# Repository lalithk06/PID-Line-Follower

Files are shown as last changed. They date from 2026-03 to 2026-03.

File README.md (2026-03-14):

# 🤖 ESP32 Line Follower Robot — Hardware Design
*A compact and efficient line follower robot built using the ESP32*

<p align="center">
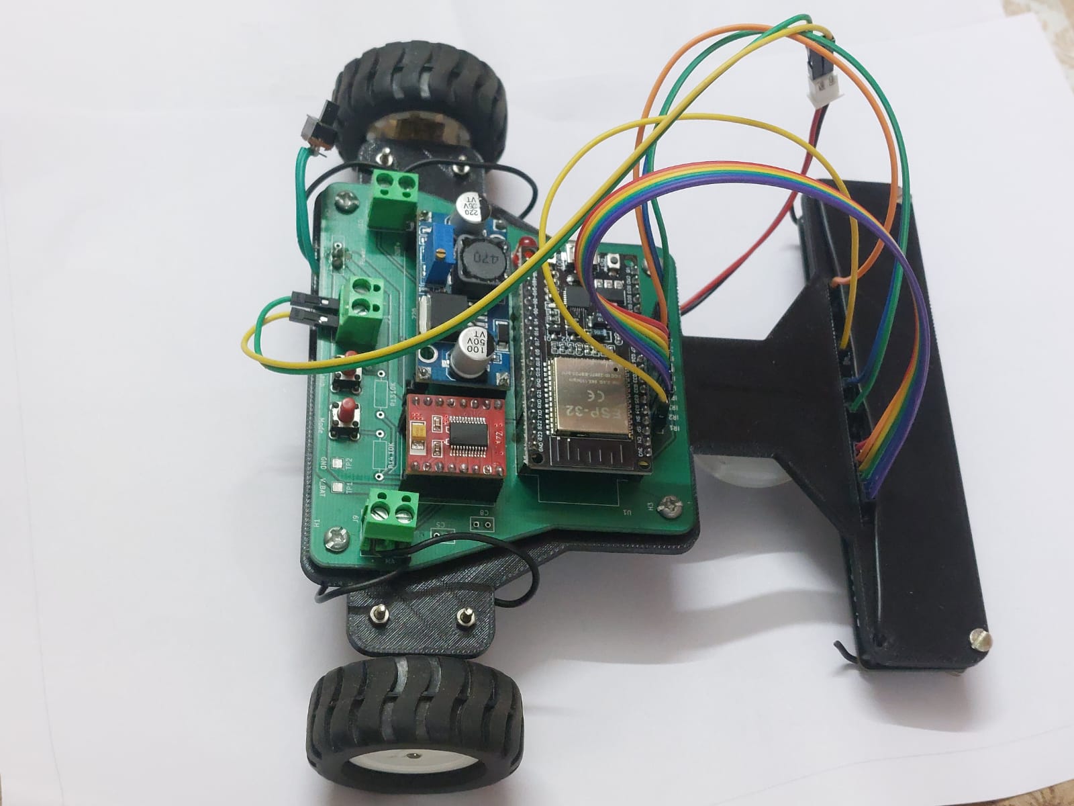
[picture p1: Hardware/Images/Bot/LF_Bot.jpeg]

</p>

## Demo
<p align="center">
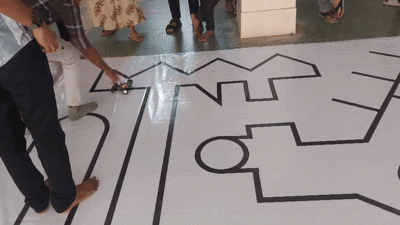
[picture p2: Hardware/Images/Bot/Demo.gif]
  
</p>

This project showcases the schematic and PCB design of a reliable line follower robot capable of high-speed tracking with stable power delivery and clean motor control. It is designed as a practical exploration of real-world embedded hardware development and PCB design workflows.

---

## 📂 Repository Structure
```
PID-Line-Follower
│
├── Firmware
│   └── Arduino_Code
│
├── Hardware
│   ├── Images
│   ├── Schematic
│   ├── Datasheet
│   └── Pin_Mapping
│
├── README.md
└── .gitignore
```
---

## Working Principle

- The ESP32 DevKit (38-pin) acts as the main controller.
- An 8-channel IR sensor array detects the line:
  - 6 sensors operate in analog mode for precise position tracking.
  - 2 sensors operate in digital mode for edge detection.
- The TB6612FNG motor driver controls two DC motors with efficient PWM-based speed regulation.
- A LM2596 buck converter steps down the battery voltage to provide a stable **3.3V rail** for the ESP32 and logic circuitry.
- Two push buttons allow:
  - Calibration mode – tune sensor thresholds.
  - Mode selection – switch between operating behaviors.
- Decoupling capacitors and a ground plane ensure noise reduction and power stability.

---

## 🎯 Objective

To design and develop a robust hardware platform for a line follower robot that demonstrates:

- Proper power architecture  
- Motor driver integration  
- Mixed analog/digital sensing  
- Clean PCB layout practices  
- Expandable embedded design  

---

## Hardware Overview

| No. | Component | Role |
|---|---|---|
| 1 | ESP32 DevKit (38-pin) | Main microcontroller with Wi-Fi & BLE |
| 2 | TB6612FNG | Dual motor driver |
| 3 | LM2596 Buck Converter | Efficient voltage regulation |
| 4 | IR Sensor Array (8-channel) | Line detection |
| 5 | Push Buttons (2x) | Calibration & mode selection |
| 6 | Battery Input + Slide Switch | Power control |
| 7 | Capacitors | Filtering & decoupling |
| 8 | Mounting Holes | Mechanical stability |

---

## Power Architecture

**Battery → Slide Switch → LM2596 Buck → 3.3V Rail**

Design considerations:

✅ Wide power traces for motor current  
✅ Dedicated ground plane  
✅ Local decoupling near driver and ESP32  
✅ Separate motor and logic routing where possible  

---

## Firmware

The robot firmware is written for the ESP32 using the Arduino framework.

Key features of the control software:

• Multi-sensor line detection  
• Adaptive speed control  
• PID-based steering correction  
• Calibration routines for sensor tuning  

Firmware source code is available in the `Firmware` directory.

---

## 📷 Preview

### 🖼️ Schematic  
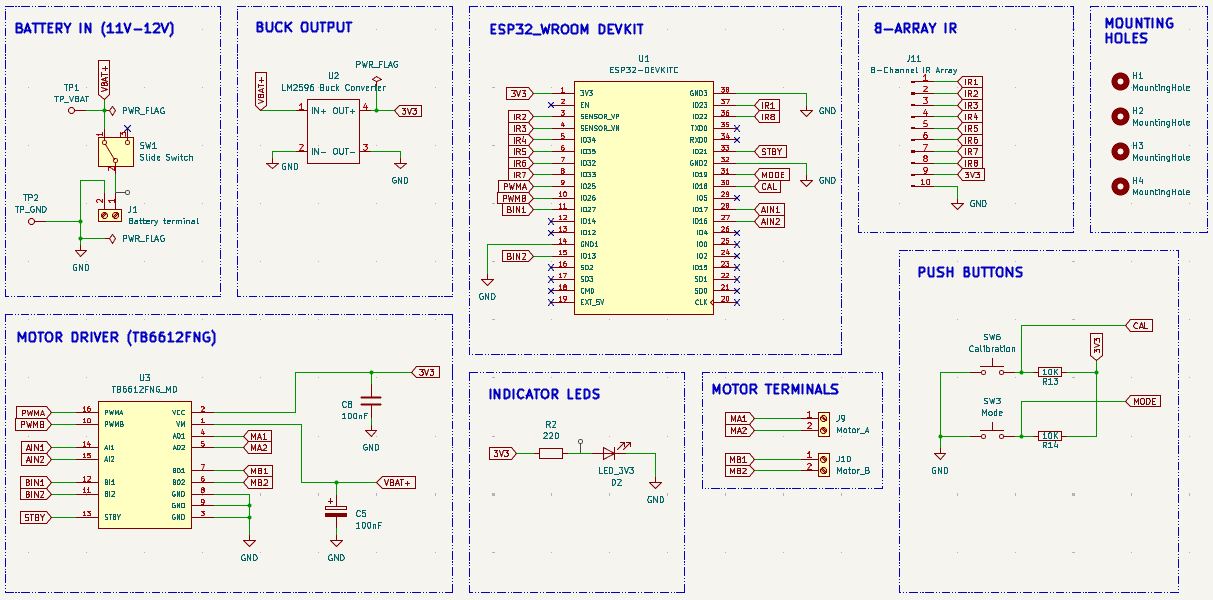
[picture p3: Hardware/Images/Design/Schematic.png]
Schematic


### 📐 PCB Layout  
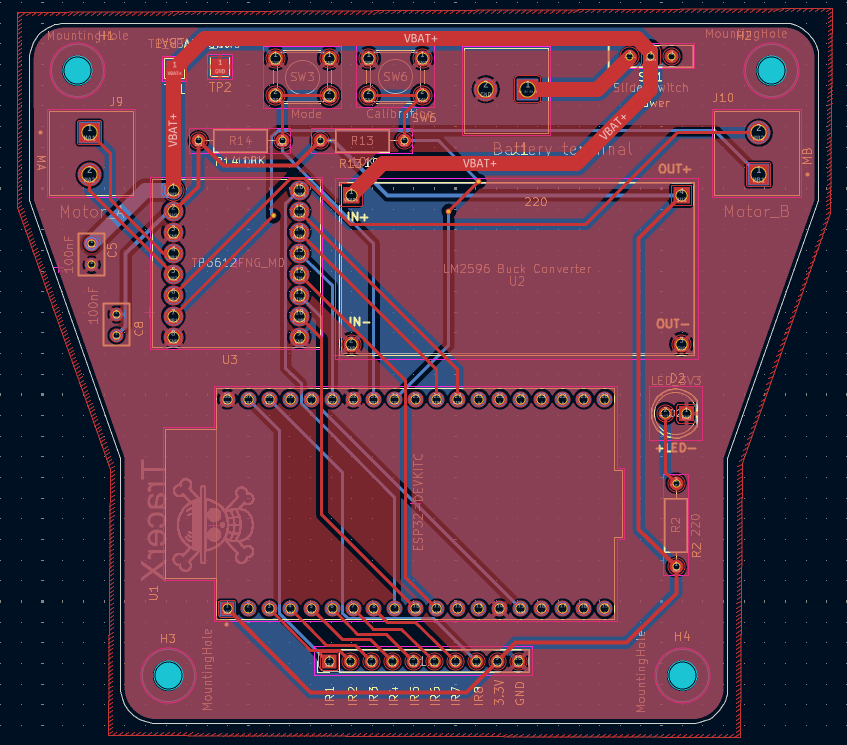
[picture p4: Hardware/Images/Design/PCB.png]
PCB


### 🧊 3D View  
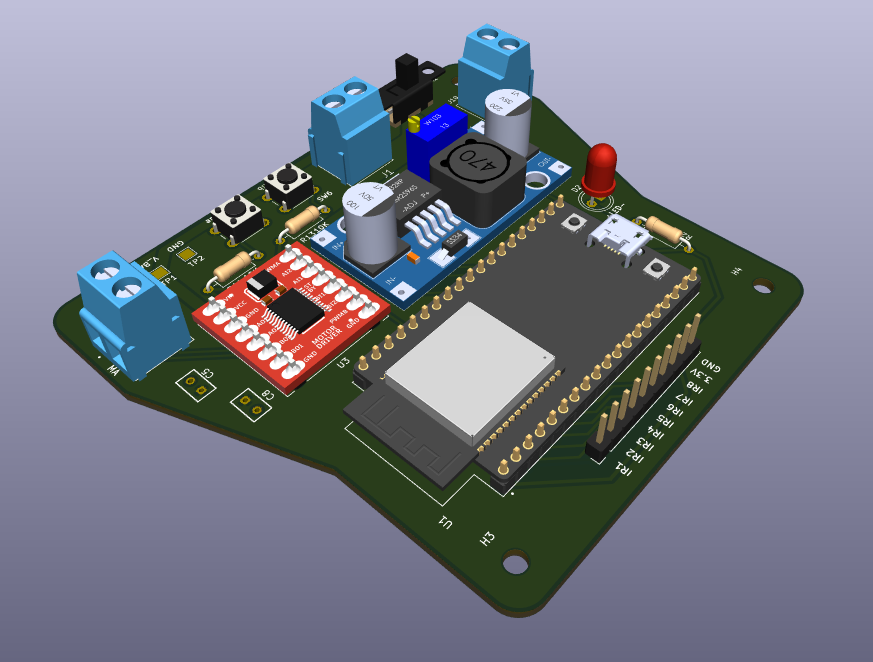
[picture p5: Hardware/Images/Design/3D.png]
3D


---

## Key Features

✅ Stable buck-regulated power supply  
✅ High-efficiency TB6612FNG motor control  
✅ Mixed analog + digital sensor interface  
✅ Compact 2-layer PCB  
✅ Ground plane for noise reduction  
✅ Designed following practical PCB routing guidelines  

---

## Design Notes

- Motor traces are sized to handle higher current.
- Ground return paths are optimized using copper pour.
- Mounting holes are included for chassis integration.
- Connectors are placed for easy wiring and maintenance.

---

## Future Improvements

- PID tuning for smoother tracking  
- Encoder-based speed feedback  
- Bluetooth / Wi-Fi telemetry  
- Battery voltage monitoring  
- On-board charging circuit  
- Custom buck stage instead of module  
- Fully integrated motor + sensor board  

---

## 📚 Learning Outcomes

This project helped strengthen understanding of:

- Power electronics in embedded systems  
- PCB stackup and routing  
- Grounding strategies  
- Motor driver layout considerations  
- Hardware debugging practices

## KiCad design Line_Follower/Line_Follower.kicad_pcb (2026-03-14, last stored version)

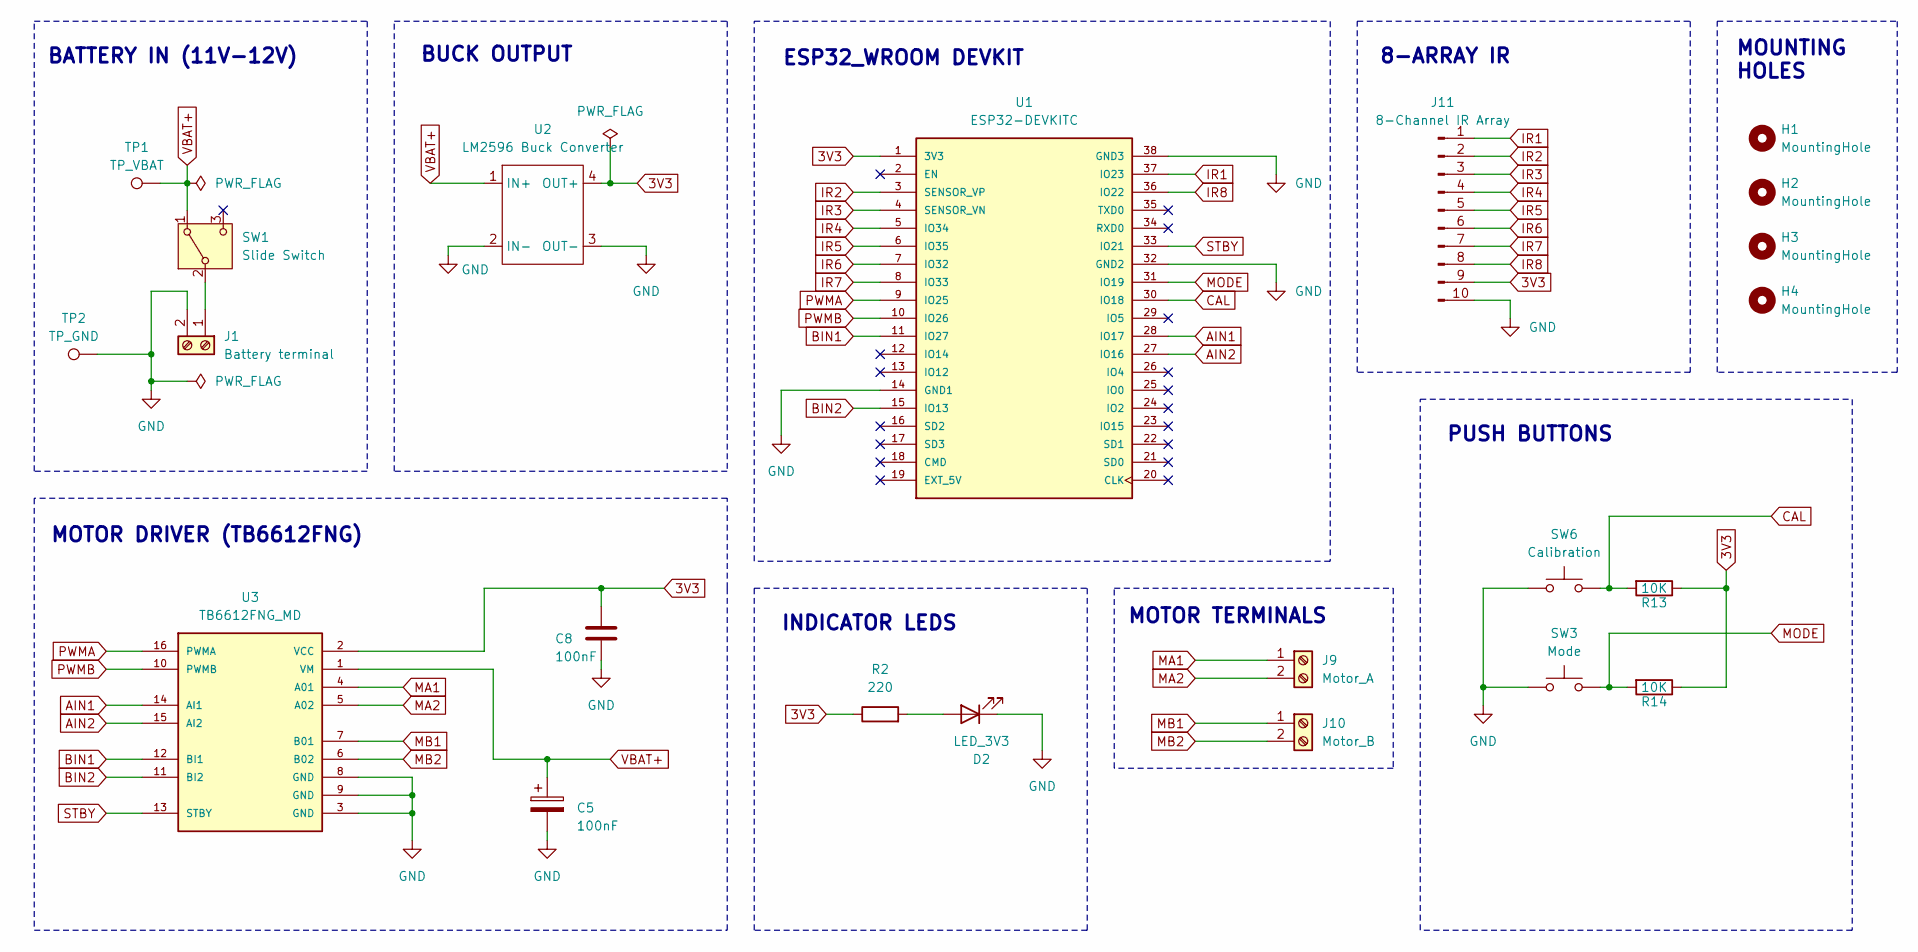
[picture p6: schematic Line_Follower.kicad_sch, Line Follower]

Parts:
C5, C8: 100nF; C320C
D2: LED_3V3; LED_D5.0mm
H1, H2, H3, H4: MountingHole; MountingHole_3.2mm_M3
J1: Battery terminal; CUI_TB007-508-02BE
J9: Motor_A; CUI_TB007-508-02BE
J10: Motor_B; CUI_TB007-508-02BE
J11: 8-Channel IR Array; PinHeader_1x10_P2.54mm_Vertical
R2: 220; R_Axial_DIN0207_L6.3mm_D2.5mm_P10.16mm_Horizontal
R13, R14: 10K; R_Axial_DIN0207_L6.3mm_D2.5mm_P10.16mm_Horizontal
SW1: Slide Switch; SW_Slide-03_Wuerth-WS-SLTV_10x2.5x6.4_P2.54mm
SW3: Mode; SW_PUSH_6mm
SW6: Calibration; SW_PUSH_6mm
TP1: TP_VBAT; TestPoint_Pad_2.0x2.0mm
TP2: TP_GND; TestPoint_Pad_2.0x2.0mm
U1: ESP32-DEVKITC; MODULE_ESP32-DEVKITC; PARTREV N/A
U2: LM2596 Buck Converter; LM2596_Buck_Module
U3: TB6612FNG_MD; TB6612FNG_Driver

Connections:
3V3: C8.1, J11.9, R2.1, R13.1, R14.1, U1.1 (3V3), U2.4 (OUT+), U3.2 (VCC)
AIN1: U1.28 (IO17), U3.14 (AI1)
AIN2: U1.27 (IO16), U3.15 (AI2)
BIN1: U1.11 (IO27), U3.12 (BI1)
BIN2: U1.15 (IO13), U3.11 (BI2)
CAL: R13.2, SW6.2, U1.30 (IO18)
GND: C5.2, C8.2, D2.1 (K), J1.2, J11.10, SW3.1, SW6.1, TP2.1, U1.14 (GND1), U1.32 (GND2), U1.38 (GND3), U2.2 (IN-), U2.3 (OUT-), U3.3 (GND), U3.8 (GND), U3.9 (GND)
IR1: J11.1, U1.37 (IO23)
IR2: J11.2, U1.3 (SENSOR_VP)
IR3: J11.3, U1.4 (SENSOR_VN)
IR4: J11.4, U1.5 (IO34)
IR5: J11.5, U1.6 (IO35)
IR6: J11.6, U1.7 (IO32)
IR7: J11.7, U1.8 (IO33)
IR8: J11.8, U1.36 (IO22)
MA1: J9.1, U3.4 (A01)
MA2: J9.2, U3.5 (A02)
MB1: J10.1, U3.7 (B01)
MB2: J10.2, U3.6 (B02)
MODE: R14.2, SW3.2, U1.31 (IO19)
unnamed: D2.2 (A), R2.2
unnamed: J1.1, SW1.2 (B)
PWMA: U1.9 (IO25), U3.16 (PWMA)
PWMB: U1.10 (IO26), U3.10 (PWMB)
STBY: U1.33 (IO21), U3.13 (STBY)
VBAT+: C5.1, SW1.1 (A), TP1.1, U2.1 (IN+), U3.1 (VM)

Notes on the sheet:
BUCK OUTPUT
8-ARRAY IR
MOUNTING HOLES
MOTOR TERMINALS
INDICATOR LEDS
BATTERY IN (11V-12V)
PUSH BUTTONS
MOTOR DRIVER (TB6612FNG)
ESP32_WROOM DEVKIT

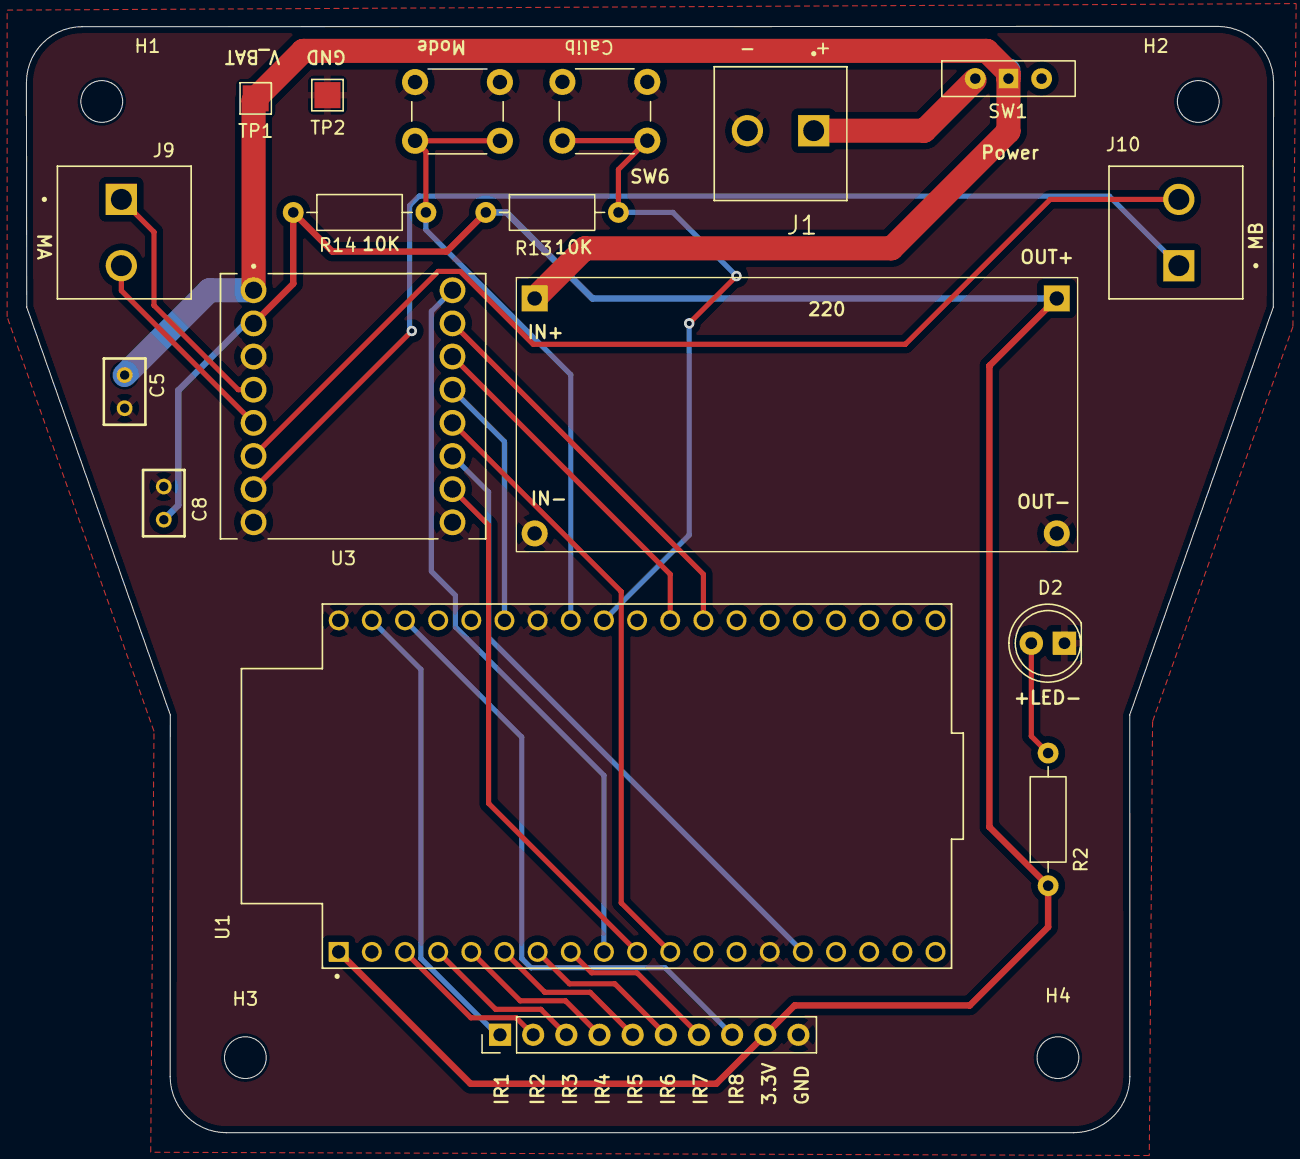
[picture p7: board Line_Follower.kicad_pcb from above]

Board: 2 copper layers, 95.5 x 84.7 mm, 22 parts (0 on the bottom side), 26 nets.

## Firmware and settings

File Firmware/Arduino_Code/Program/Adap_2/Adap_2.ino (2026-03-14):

#define AIN1 17
#define AIN2 16
#define BIN1 27
#define BIN2 13
#define PWMA 25
#define PWMB 26
#define STBY 21

#define IR1 23
#define IR8 22
int IR_analog[6] = {36, 39, 34, 35, 32, 33};

const int THRESHOLD = 85;

float Kp = 40.0f;
float Ki = 0.0f;
float Kd = 8.8f;

float integral      = 0;
float lastError     = 0;
float filteredError = 0;

const float sensorPos[6] = {-3.5f, -2.0f, -0.5f, 0.5f, 2.0f, 3.5f};

int   baseSpeed       = 130;
int   maxSpeed        = 255;
int   MIN_CURVE_SPEED = 60;

const float SPEED_KP = 20.0f;

int currentSpeed = 0;
const int rampStep  = 10;
const int rampDelay = 10;
unsigned long lastRampTime = 0;

const float DEADBAND = 0.08f;

// ================= RECOVERY =================
unsigned long lastLineSeenTime = 0;
const unsigned long DASHED_GAP_TIMEOUT = 400;
const unsigned long SPIN_TIMEOUT       = 500;
const int REVERSE_SPEED = 70;

enum RecoveryPhase {
  ON_LINE,
  DASHED_GAP,
  SPINNING,
  REVERSING,
  SPINNING2,
};

RecoveryPhase recoveryPhase    = ON_LINE;
unsigned long recoveryPhaseStart = 0;
int spinDirection = 0;

// ================= SENSOR DATA =================
int rawADC[6];
int IR_inner[6];
int IR_left  = 0;
int IR_right = 0;

unsigned long lastLoopTime = 0;
float dt = 0.005f;

bool running = false;

// ============================================================
void setup(){
  Serial.begin(115200);

  pinMode(AIN1, OUTPUT); pinMode(AIN2, OUTPUT);
  pinMode(BIN1, OUTPUT); pinMode(BIN2, OUTPUT);
  pinMode(STBY, OUTPUT);
  digitalWrite(STBY, HIGH);

  pinMode(IR1, INPUT);
  pinMode(IR8, INPUT);
  for(int i = 0; i < 6; i++) pinMode(IR_analog[i], INPUT);

  ledcSetup(0, 2000, 8); ledcAttachPin(PWMA, 0);
  ledcSetup(1, 2000, 8); ledcAttachPin(PWMB, 1);

  stopMotors();

  running            = true;
  currentSpeed       = 0;
  lastRampTime       = millis();
  lastLineSeenTime   = millis();
  lastLoopTime       = micros();
  integral           = 0;
  lastError          = 0;
  filteredError      = 0;
  recoveryPhase      = ON_LINE;
}

// ============================================================
void drive(int L, int R){
  L = constrain(L, -maxSpeed, maxSpeed);
  R = constrain(R, -maxSpeed, maxSpeed);

  if(L >= 0){ digitalWrite(AIN1, HIGH); digitalWrite(AIN2, LOW);  }
  else       { digitalWrite(AIN1, LOW);  digitalWrite(AIN2, HIGH); L = -L; }
  ledcWrite(0, L);

  if(R >= 0){ digitalWrite(BIN1, HIGH); digitalWrite(BIN2, LOW);  }
  else       { digitalWrite(BIN1, LOW);  digitalWrite(BIN2, HIGH); R = -R; }
  ledcWrite(1, R);
}

void stopMotors(){
  ledcWrite(0, 0); ledcWrite(1, 0);
  digitalWrite(AIN1, LOW); digitalWrite(AIN2, LOW);
  digitalWrite(BIN1, LOW); digitalWrite(BIN2, LOW);
}

// ============================================================
void readSensors(){
  IR_left  = (digitalRead(IR1) == HIGH) ? 1 : 0;
  IR_right = (digitalRead(IR8) == HIGH) ? 1 : 0;

  for(int i = 0; i < 6; i++){
    rawADC[i]   = analogRead(IR_analog[i]);
    IR_inner[i] = (rawADC[i] > THRESHOLD) ? 1 : 0;
  }
}

// ============================================================
float computeError(){
  float weightedSum = 0;
  float totalWeight = 0;

  for(int i = 0; i < 6; i++){
    float strength = (float)rawADC[i] - (float)THRESHOLD;
    if(strength < 0) strength = 0;
    weightedSum += sensorPos[i] * strength;
    totalWeight += strength;
  }

  if(totalWeight < 10) return lastError;

  lastLineSeenTime = millis();
  return weightedSum / totalWeight;
}

// ============================================================
bool anyInnerOnLine(){
  for(int i = 0; i < 6; i++) if(IR_inner[i]) return true;
  return false;
}

// ============================================================
void handleSpeedRamp(){
  if(millis() - lastRampTime >= rampDelay){
    lastRampTime = millis();
    if(currentSpeed < baseSpeed) currentSpeed += rampStep;
  }
}

// ============================================================
bool handleRecovery(){

  bool innerSeen = anyInnerOnLine();

  if(innerSeen){
    if(recoveryPhase != ON_LINE){
      integral      = 0;
      filteredError = 0;
      lastError     = 0;
      recoveryPhase = ON_LINE;
    }
    lastLineSeenTime = millis();
    return false;
  }

  // Line is lost — start recovery
  if(recoveryPhase == ON_LINE){
    spinDirection      = (lastError >= 0) ? 1 : -1;
    recoveryPhase      = SPINNING;
    recoveryPhaseStart = millis();
  }

  unsigned long phaseElapsed = millis() - recoveryPhaseStart;

  switch(recoveryPhase){

    case DASHED_GAP:
      {
        float correction = lastError * Kp * 0.3f;
        int L = constrain(currentSpeed + (int)correction, 0, maxSpeed);
        int R = constrain(currentSpeed - (int)correction, 0, maxSpeed);
        drive(L, R);
        if(phaseElapsed >= DASHED_GAP_TIMEOUT){
          recoveryPhase      = SPINNING;
          recoveryPhaseStart = millis();
        }
      }
      break;

    case SPINNING:
      if(phaseElapsed < 100){
        stopMotors();          // brief stop before spin
      } else {
        if(spinDirection > 0) drive( 130, -130);
        else                  drive(-130,  130);
      }
      break;

    default:
      break;
  }

  return true;
}

// ============================================================
enum TurnState { TURN_NONE, TURNING_LEFT, TURNING_RIGHT };
TurnState sharpTurnState = TURN_NONE;
unsigned long turnStartTime = 0;
const unsigned long SHARP_TURN_DURATION = 500;

// ============================================================
// activeSpeed passed in — pivot uses max(activeSpeed, 140)
// so adaptive speed applies but pivot never goes below 140
// ============================================================
bool handleJunction(int activeSpeed) {

  if(fabs(filteredError) > 0.7f) return false;

  int leftCount  = IR_inner[0] + IR_inner[1] + IR_inner[2];
  int rightCount = IR_inner[3] + IR_inner[4] + IR_inner[5];
  int totalInner = leftCount + rightCount;

  if(sharpTurnState != TURN_NONE) return false;

  bool exitLeft  = (IR_left  == 1) && (totalInner >= 4) && rightCount >= 1;
  bool exitRight = (IR_right == 1) && (totalInner >= 4) && leftCount  >= 1;

  if(!exitLeft && !exitRight) return false;

  integral = 0; filteredError = 0; lastError = 0;

  int pivotSpeed = max(activeSpeed, 140);  // adaptive but never below 140

  if(exitRight){
    drive( pivotSpeed, -pivotSpeed);
    return true;
  }
  if(exitLeft){
    drive(-pivotSpeed,  pivotSpeed);
    return true;
  }

  return false;
}

// ============================================================
bool handleSharpTurn() {

  int leftCount  = IR_inner[0] + IR_inner[1] + IR_inner[2];
  int rightCount = IR_inner[3] + IR_inner[4] + IR_inner[5];
  int totalCount = leftCount + rightCount;

  if (anyInnerOnLine() && IR_left == 0 && IR_right == 0)
  return false;

  // ---- Detect entry into sharp turn ----
  if (sharpTurnState == TURN_NONE) {

    if (leftCount >= 2 && rightCount <= 1 && IR_right == 0) {
      sharpTurnState = TURNING_LEFT;
      turnStartTime  = millis();
      integral = 0; filteredError = 0; lastError = 0;
      return true;
    }

    if (rightCount >= 2 && leftCount <= 1 && IR_left == 0) {
      sharpTurnState = TURNING_RIGHT;
      turnStartTime  = millis();
      integral = 0; filteredError = 0; lastError = 0;
      return true;
    }

    return false;
  }

  // ---- Execute the maneuver ----
  unsigned long elapsed = millis() - turnStartTime;

  bool recentered = elapsed > 100 &&           // minimum turn time — can't exit before this
                    (IR_inner[2] || IR_inner[3]) &&
                    leftCount > 0 && rightCount > 0;

  if (recentered || elapsed > SHARP_TURN_DURATION) {
    sharpTurnState = TURN_NONE;
    integral = 0; filteredError = 0; lastError = 0;
    return false;
  }

  if (sharpTurnState == TURNING_LEFT) {
    drive(-160, 160);
  } else {
    drive(160, -160);
  }

  return true;
}

// ============================================================
void pidControl(){

  readSensors();

  unsigned long now = micros();
  dt = (now - lastLoopTime) / 1000000.0f;
  dt = constrain(dt, 0.001f, 0.05f);
  lastLoopTime = now;

  // ── Compute error and activeSpeed FIRST ──
  // so all handlers benefit from adaptive speed
  float error = computeError();
  if(fabsf(error) < DEADBAND) error = 0.0f;
  filteredError = 0.2f * filteredError + 0.8f * error;

  int adaptiveSpeed = baseSpeed - (int)(fabsf(filteredError) * SPEED_KP);
  adaptiveSpeed = constrain(adaptiveSpeed, MIN_CURVE_SPEED, baseSpeed);
  int activeSpeed = min(currentSpeed, adaptiveSpeed);

  // ── Special handlers — all receive activeSpeed ──
  if(handleSharpTurn()) return;
  if(handleJunction(activeSpeed))  return;
  if(handleRecovery())             return;

  // ── Normal PID ──
  float P_term = Kp * filteredError;
  float D_term = Kd * (filteredError - lastError);

  if(anyInnerOnLine())
    integral += filteredError * dt;
  else
    integral = 0;
  integral = constrain(integral, -30.0f, 30.0f);
  float I_term = Ki * integral;

  float correction = P_term + I_term + D_term;
  lastError = filteredError;

  int L = activeSpeed + (int)correction;
  int R = activeSpeed - (int)correction;

  int maxVal = max(abs(L), abs(R));
  if(maxVal > maxSpeed){
    L = (L * maxSpeed) / maxVal;
    R = (R * maxSpeed) / maxVal;
  }

  drive(L, R);
}

// ============================================================
void loop(){
  if(running){
    handleSpeedRamp();
    pidControl();
  } else {
    stopMotors();
  }
}

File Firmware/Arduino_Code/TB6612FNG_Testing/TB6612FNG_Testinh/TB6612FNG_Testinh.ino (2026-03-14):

// ========= MOTOR PINS =========
#define PWMA 25
#define PWMB 26
#define AIN1 17
#define AIN2 16
#define BIN1 27
#define BIN2 13
#define STBY 21

// ========= PWM SETTINGS =========
#define freq 1000
#define resolution 8

#define channelA 0
#define channelB 1

int speedMotor = 180; // 0-255

void setup() {

  pinMode(AIN1, OUTPUT);
  pinMode(AIN2, OUTPUT);
  pinMode(BIN1, OUTPUT);
  pinMode(BIN2, OUTPUT);
  pinMode(STBY, OUTPUT);

  digitalWrite(STBY, HIGH); // Wake driver

  // PWM setup
  ledcSetup(channelA, freq, resolution);
  ledcAttachPin(PWMA, channelA);

  ledcSetup(channelB, freq, resolution);
  ledcAttachPin(PWMB, channelB);
}

// ================= MOTOR FUNCTIONS =================

void forward() {

  digitalWrite(AIN1, HIGH);
  digitalWrite(AIN2, LOW);

  digitalWrite(BIN1, HIGH);
  digitalWrite(BIN2, LOW);

  ledcWrite(channelA, speedMotor);
  ledcWrite(channelB, speedMotor);
}

void backward() {

  digitalWrite(AIN1, LOW);
  digitalWrite(AIN2, HIGH);

  digitalWrite(BIN1, LOW);
  digitalWrite(BIN2, HIGH);

  ledcWrite(channelA, speedMotor);
  ledcWrite(channelB, speedMotor);
}

void left() {

  ledcWrite(channelA, 80);   // slow left motor
  ledcWrite(channelB, 200);  // fast right motor

  digitalWrite(AIN1, HIGH);
  digitalWrite(AIN2, LOW);

  digitalWrite(BIN1, HIGH);
  digitalWrite(BIN2, LOW);
}

void right() {

  ledcWrite(channelA, 200);
  ledcWrite(channelB, 80);

  digitalWrite(AIN1, HIGH);
  digitalWrite(AIN2, LOW);

  digitalWrite(BIN1, HIGH);
  digitalWrite(BIN2, LOW);
}

void stopMotor() {

  ledcWrite(channelA, 0);
  ledcWrite(channelB, 0);
}

// ================= TEST LOOP =================

void loop() {

  forward();
  delay(3000);

  stopMotor();
  delay(1000);

  backward();
  delay(3000);

  stopMotor();
  delay(1000);

  left();
  delay(2000);

  right();
  delay(2000);

  stopMotor();
  delay(4000);
}

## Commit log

2026-02-08 Schematics updated
    [500SSP1S2M2QEA.STEP, 500SSP1S2M2QEA.step, LF_GPIO_Mapping.xlsx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]
2026-02-08 PCB updated
2026-02-08 Schematic edited
    [Line_Follower.kicad_sch]
2026-02-08 Net classes assigned
    [Line_Follower.kicad_sch]
2026-02-08 Footprint added, PCB aligned
    [Line_Follower.kicad_pcb, Line_Follower.kicad_sch]
2026-02-09 PCB edge cuts designed
    [Line_Follower.kicad_pcb]
2026-02-10 PCB edited
    [Line_Follower.kicad_pcb, Line_Follower.kicad_sch]
2026-02-10 3D models added
    [LM2596 DC-DC Buck Converter Module.SLDPRT, LM2596_pin.stp, Line_Follower.kicad_pcb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]
2026-02-11 3D model
    [Line_Follower.kicad_pcb]
2026-02-11 Routing started
    [Line_Follower.kicad_pcb, Line_Follower.kicad_sch, freerouting.dsn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]
2026-02-11 Routing done
    [C320C104M5U5TA.step, EEUTA1V102.step, Line_Follower.kicad_pcb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]
2026-02-11 Routing optimised
    [Line_Follower.kicad_pcb]
2026-02-12 Routing modified
    [Line_Follower-B_Cu.dxf, Line_Follower-B_Mask.dxf, Line_Follower-B_Paste.dxf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]
2026-02-13 File updated
    [Line_Follower-B_Cu.dxf, Line_Follower-B_Mask.dxf, Line_Follower-B_Paste.dxf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]
2026-02-14 Capacitors removed
    [EEUFS1V102LB.step, Line_Follower.kicad_pcb, Line_Follower.kicad_sch]
2026-02-14 Gerber created
    [Line_Follower-B_Cu.gbr, Line_Follower-B_Mask.gbr, Line_Follower-B_Paste.gbr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]
2026-03-14 Plot updated
    [LF_Chassis.f3d, chassis.f3d]
2026-03-14 Removed manufacturing and CAD files
2026-03-14 Reconstructed repo firmware and hardware folders
    [LF_GPIO_Mapping.xlsx, Line_Follower.kicad_pcb, Line_Follower.kicad_sch]
2026-03-14 folders reorganised
    [LF_GPIO_Mapping.xlsx, Line_Follower.kicad_pcb, Line_Follower.kicad_sch]
